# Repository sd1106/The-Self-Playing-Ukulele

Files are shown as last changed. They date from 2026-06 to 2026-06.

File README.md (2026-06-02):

# The-Self-Playing-Ukulele
An electromechanical ukulele that reads sheet music and plays it autonomously. Four stepper motors slide fretting carriages up and down the neck, four press servos fret the strings, and four strum servos pluck them. All electronics are coordinated by an ESP32-S3 microcontroller running firmware we wrote from scratch.

## How it works: 

1. PDF Sheet Music -> 
2. Optical Music Recognition (oemer) -> 
3. MusicXML mapped to music21 (Python) -> 
4. Note/Chord mapped to String + Fret mapping ->
5. Serial commands over USB -> 
6. ESP32-S3 Firmware ->
7. Stepper Motors (position)  +  Press Servos (fret)  +  Strum Servos (pluck)

## Mechanical System Description: 
Each of the four strings has its own independent carriage that rides along the neck on a timing belt driven by a 28BYJ-48 stepper motor. The carriage holds a press servo that swings up to 90 degrees to push the string down onto the fret, then returns to 0 degrees once the note has been strummed. A separate strum servo sits near the soundhole and alternates between two angles each time it fires. It tracks whether it's currently "in" or "out" and always moves to the opposite position, so it never tries to strum from the same direction twice.

Each string has its own lookup table of 14 timing values (milliseconds) representing how long the stepper needs to run to reach each fret from the home position (open/nut end). On startup, all carriages home to position zero. When a note is requested, the firmware:

1. Looks up the target fret's position in that string's table
2. Subtracts the current stored position to get the delta
3. Runs the motor forward (positive delta) or backward (negative delta) for that many milliseconds
4. Updates the stored current position

This means "string 3, fret 7" and "string 4, fret 7" will move different physical distances, because fret spacing and belt geometry differ per string, since each has its own calibrated table.

## Hardware Components:

- ESP32-S3-WROOM-1: Main microcontroller
- 28BYJ-48 stepper motor (x4): Move fretting carriage along the neck of the ukulele
- ULN2003 driver board (x4): Drive the steppers (4 GPIO pins each)
- 180° servo motor (x4): Strum strings (alternates direction each strike)
- 180° servo motor (x4): Press strings down onto frets (0°→90°→0°)
- 5V power supply: Powers steppers and servos

*Note: The ESP32-S3-WROOM-1 is used specifically. Pin assignments in the firmware reflect this. Pins 0, 3, 45, and 46 are avoided as they are strapping/reserved pins on this module.

## Software Components: 

#### The Arduino firmware: ukulele_riptide.ino 
The main firmware runs on the ESP32-S3 and handles all real-time motor control. 
Key behaviours:

- strumAll(): fires all four strum servos. Uses a global strumState boolean to alternate direction every call, so the servo always moves to the opposite of its current position
- pressG/C/E/A: each press servo goes to 60°–90° to fret, then returns to 0° after the chord is strummed
- Chord functions (Aminor(), G(), C()):  move the correct stepper carriages to position, set press angles, then call strummingRhythm()
- strummingRhythm(): plays the Riptide strumming pattern (down down, down-up-down with timed delays)
riptide(): sequences the three chords of Riptide (Am → G → C) and loops

#### Serial-Driven Instrument Controller (ukulele_controller.ino)
The production firmware is used in conjunction with the Python pipeline. Instead of a hardcoded song, it listens for serial commands and executes them in real time, giving the host PC full control over every actuator.

- Fret positioning: a lookup table maps each fret (0–12) to an absolute half-step count using equal-temperament geometry, so fret spacing compresses naturally toward the body. Coils are de-energised after each move to prevent the ULN2003 boards from overheating
- Strum alternation: each string tracks its own toggle, so consecutive strums always go in opposite directions
- CAL / DUMP commands: jog a carriage to any position and redefine zero without re-uploading firmware (CAL), or print a full live state table for debugging (DUMP)
- Boots by homing all carriages and parking all servos, then sends READY — the Python host waits for this before sending any commands

#### Python Pipeline: ukulele_player.py
Sits on the host PC and handles the sheet music side:

1. Opens a PDF and rasterises it to a 300 DPI PNG
2. Runs oemer (optical music recognition) to produce MusicXML
3. Parses the MusicXML with music21, extracting notes, chords, rests, and tempo
4. Maps each pitch to a (string, fret) pair using standard high-G ukulele tuning (G4 · C4 · E4 · A4), choosing whichever assignment minimises carriage travel
5. Voices chords across all four strings with a greedy least-travel algorithm
6. Sends MOVE, PLUCK, and HOME commands over USB serial in time with the score's tempo

## Libraries:

- ESP32Servo: Servo control via LEDC PWM on ESP32-S3
- Stepper (Arduino built-in): 28BYJ-48 stepper 
- controlmusic21 (Python): MusicXML parsing and score analysis
- pymupdf (Python): PDF rasterisation
- pyserial (Python): USB serial communication to ESP32

## Calibration:
Each string's fret timing table needs to be measured once on your physical build:

1. Upload firmware and open Serial Monitor
2. Send HOME — all carriages drive to the nut end limit switches
3. For each string, manually time (in milliseconds) how long the motor must run to reach each of the 14 frets from home
4. Update the lookup tables in the firmware constants at the top of ukulele_riptide.ino
5. Send DUMP over serial to verify stored positions, CAL to re-run calibration mode

Because fret spacing is not uniform (it compresses toward the body) and belt geometry differs per string, each of the four tables will have different values even for the same fret number.

### Built as a Computer Science capstone project, June 2026.

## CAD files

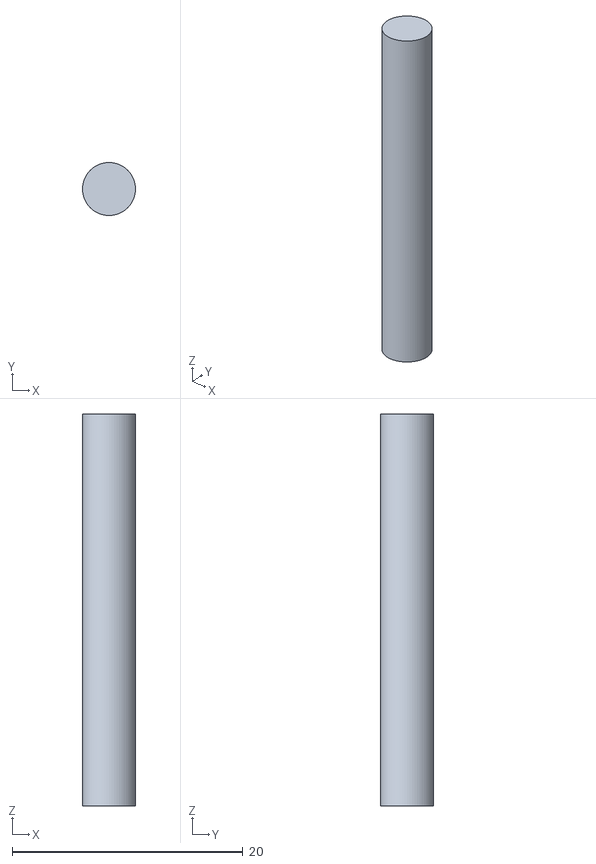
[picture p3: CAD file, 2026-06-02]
STL_Files/Axis.stl
4.60 x 4.60 x 34.0

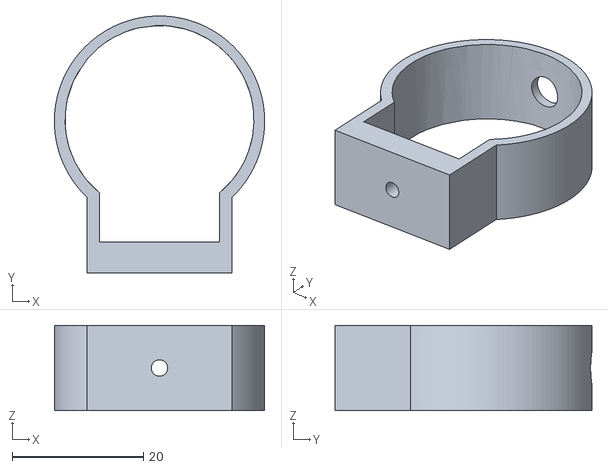
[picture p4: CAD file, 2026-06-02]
STL_Files/motor bracket.stl
32.0 x 39.1 x 13.0

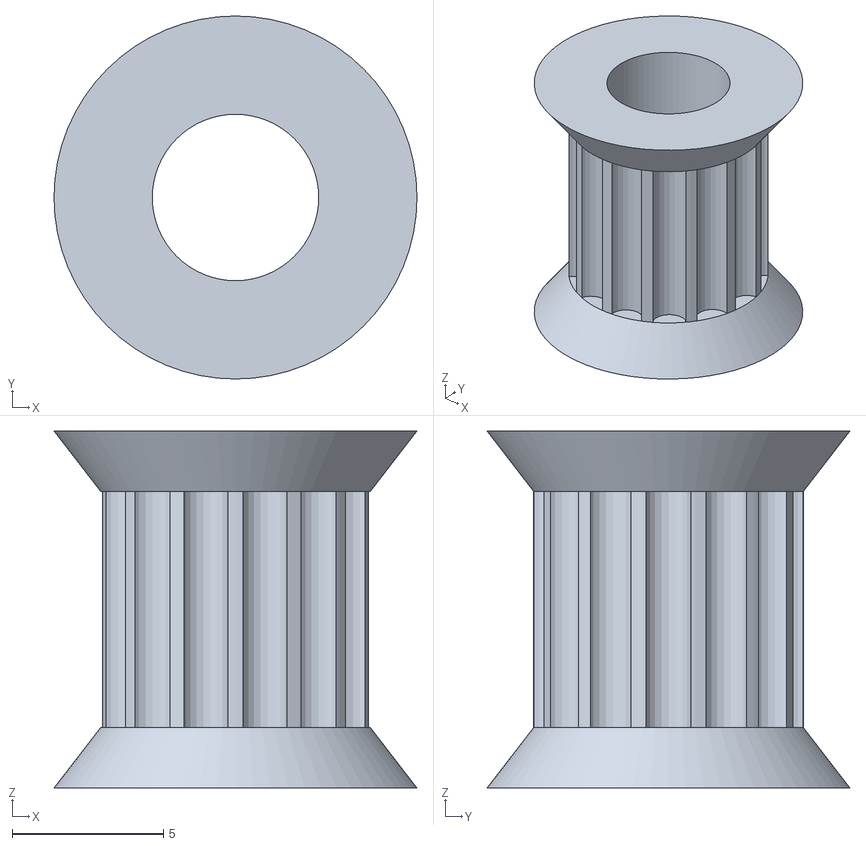
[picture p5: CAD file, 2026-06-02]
STL_Files/GT2 pully.stl
12.0 x 12.0 x 11.8

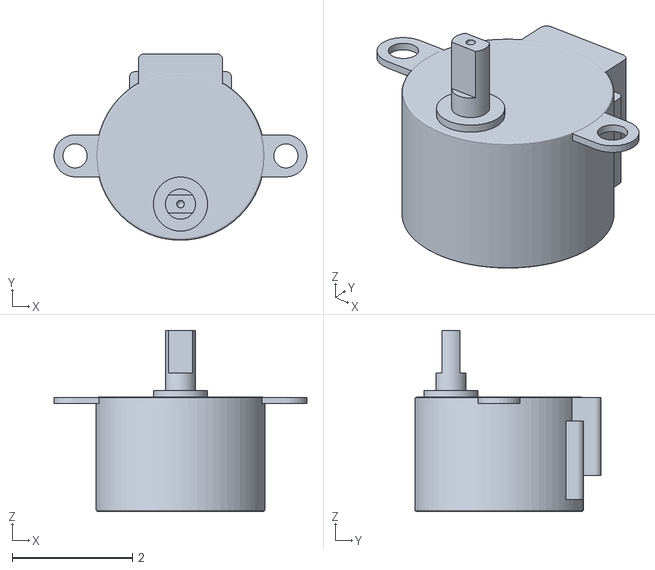
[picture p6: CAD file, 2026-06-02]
STL_Files/StepMotorModel.stl
4.20 x 3.10 x 3.01

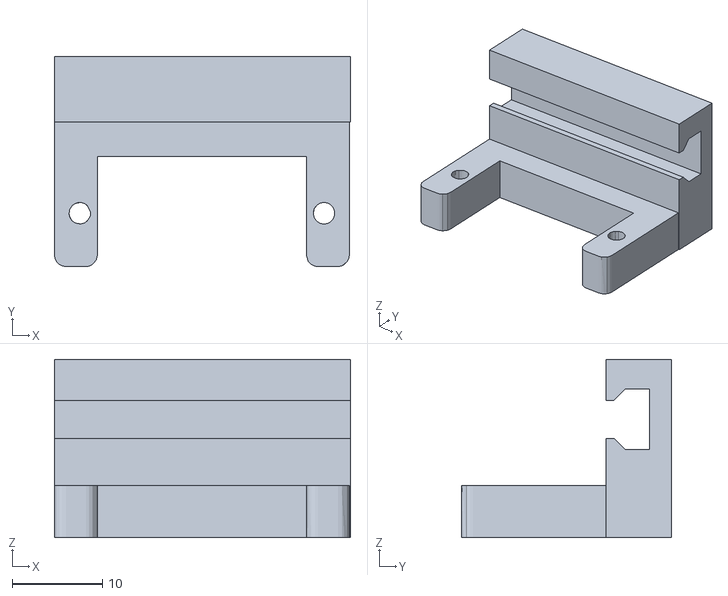
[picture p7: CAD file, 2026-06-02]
STL_Files/servo bracket.stl
32.7 x 23.2 x 19.7

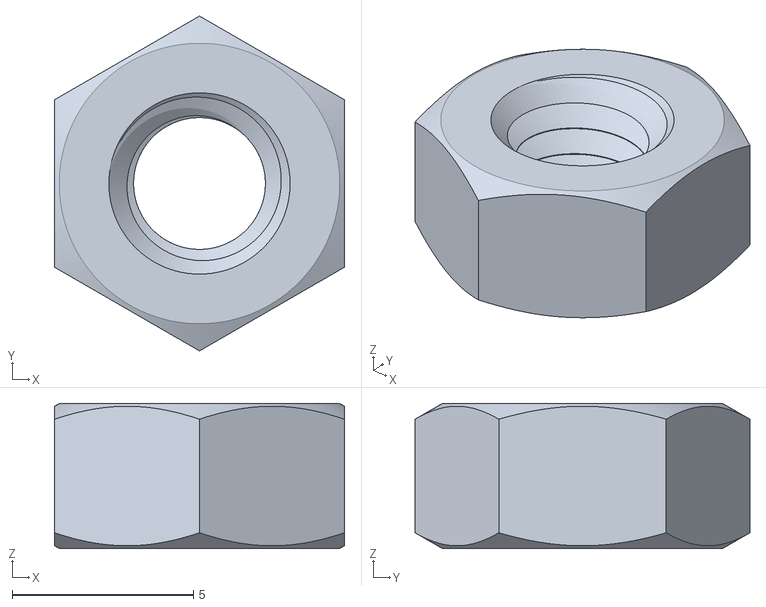
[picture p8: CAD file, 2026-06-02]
STL_Files/M5.stl
8.00 x 9.24 x 4.00

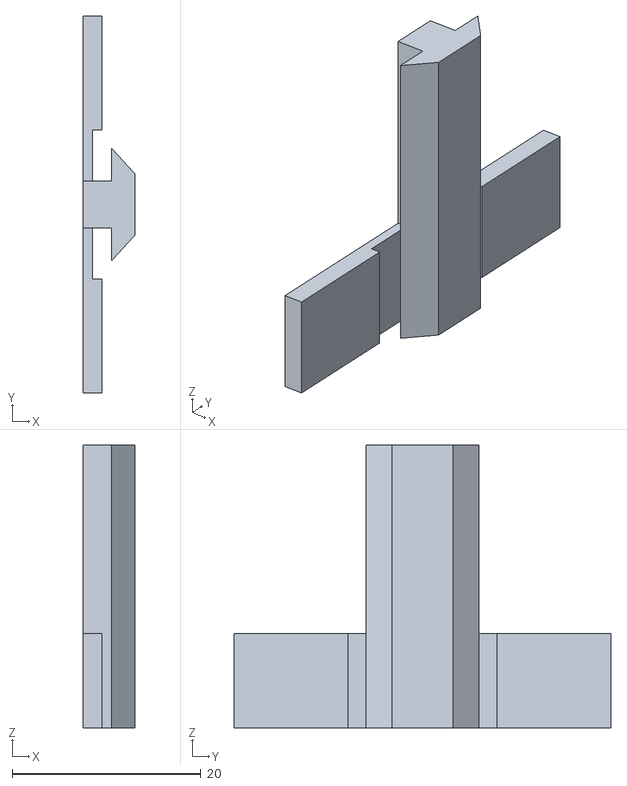
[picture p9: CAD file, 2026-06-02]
STL_Files/stepper_motor_thingy.stl
5.50 x 40.0 x 30.0

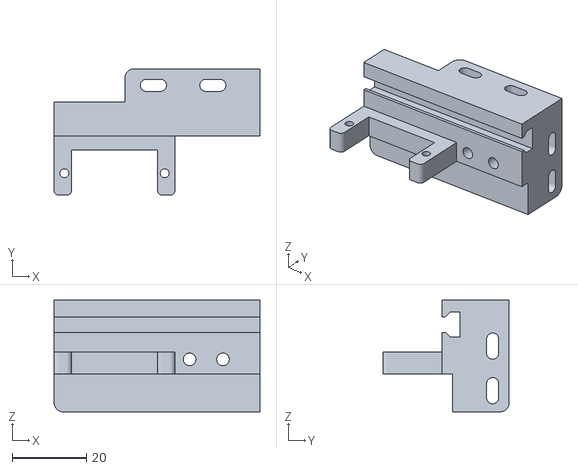
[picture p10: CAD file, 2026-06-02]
STL_Files/Motor_Bracket_Mini_Version (2).STL
55.5 x 34.0 x 30.1

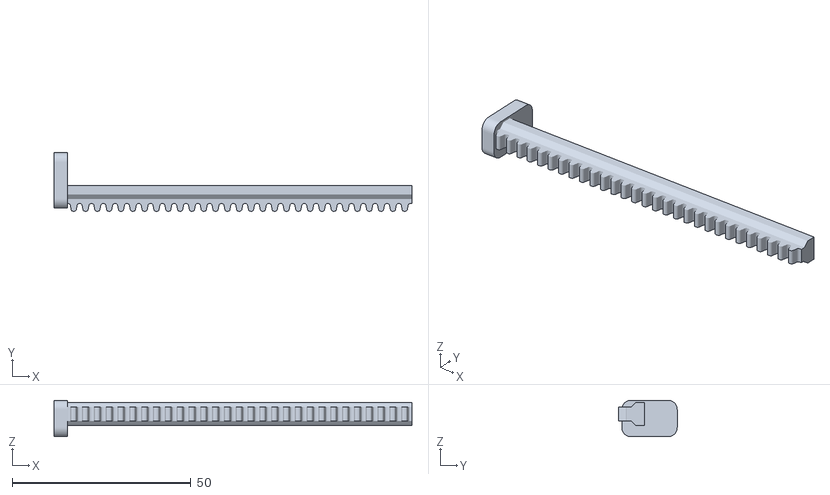
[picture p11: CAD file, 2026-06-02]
STL_Files/Pusher_100mm_Long.STL
100.0 x 16.3 x 10.2

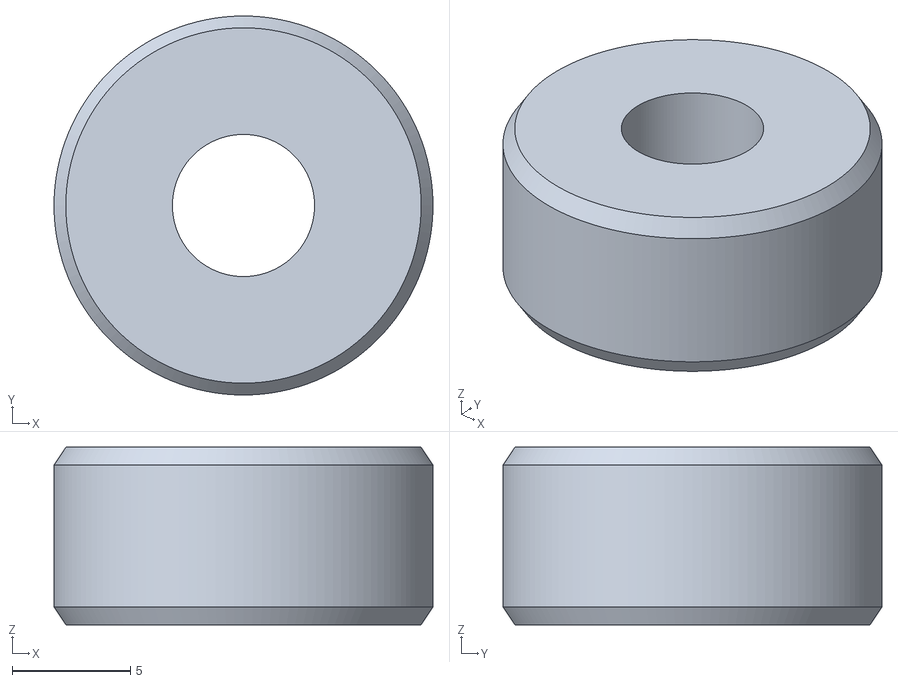
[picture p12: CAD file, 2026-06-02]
STL_Files/Glorious Elzing-Lappi.stl
16.0 x 16.0 x 7.50

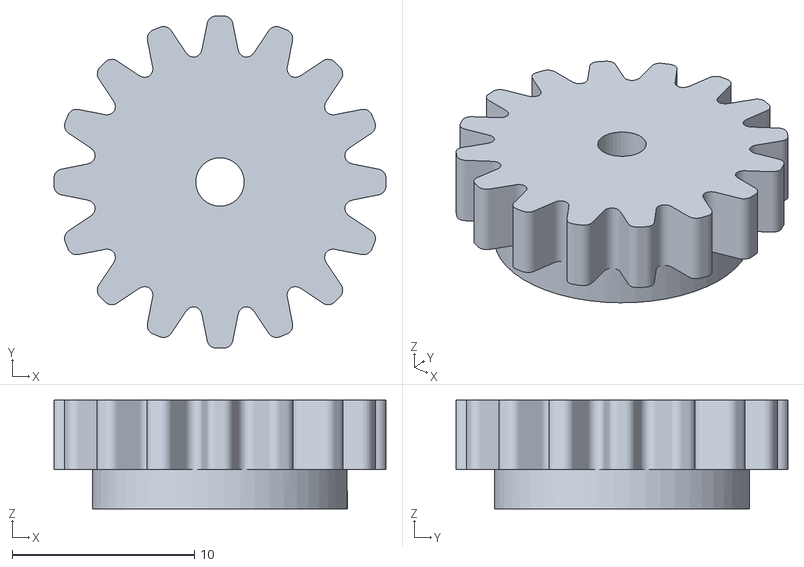
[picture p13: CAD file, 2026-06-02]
STL_Files/Pinion_Gear_Mini_Version (1).STL
18.2 x 18.2 x 5.97

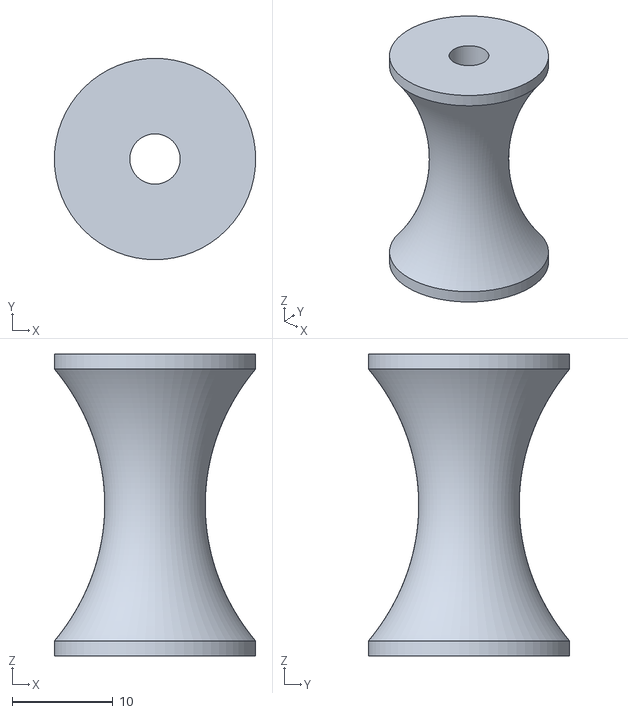
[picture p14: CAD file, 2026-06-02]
STL_Files/Roller.stl
20.0 x 20.0 x 30.0

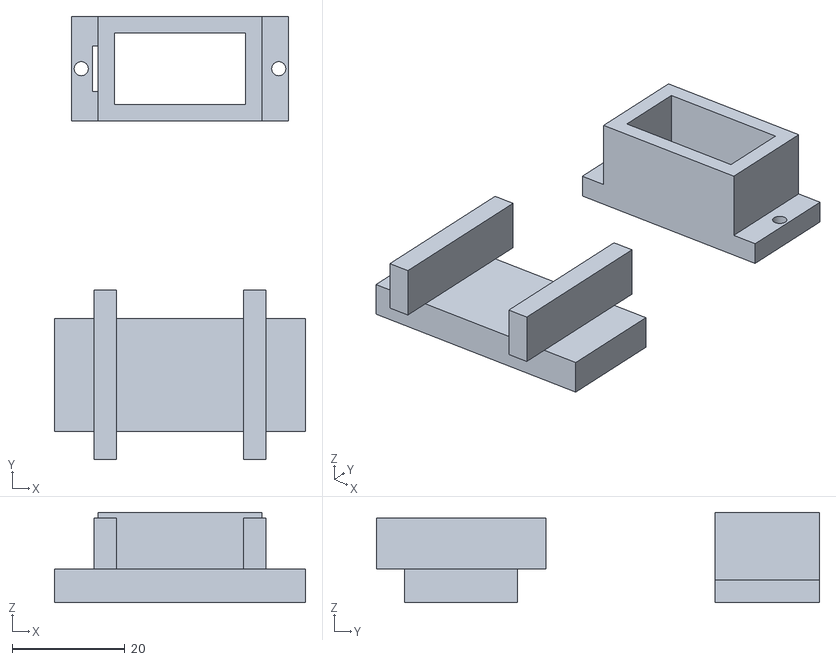
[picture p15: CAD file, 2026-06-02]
STL_Files/2Bracket.stl
44.5 x 78.5 x 16.0

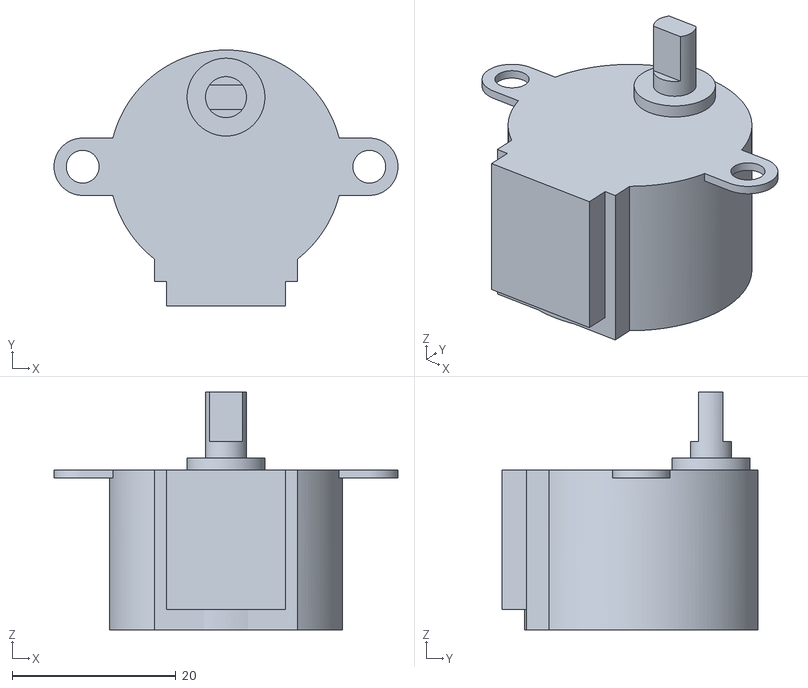
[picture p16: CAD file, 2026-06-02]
STL_Files/stepper_28byj-48.stl
42.0 x 31.2 x 29.0

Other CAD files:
STL_Files/24mm rode.stl
STL_Files/60mm rode.stl
STL_Files/5mm bolt.stl
STL_Files/9mm pusher.stl
STL_Files/Daring Robo-Fulffy (1).stl
STL_Files/Daring Robo-Fulffy (2).stl
STL_Files/Daring Robo-Fulffy (3).stl
STL_Files/Daring Robo-Fulffy (4).stl
STL_Files/Daring Robo-Fulffy (5).stl
STL_Files/Daring Robo-Fulffy (6).stl
STL_Files/Daring Robo-Fulffy.stl
STL_Files/Glorious Elzing-Lappi (1).stl
STL_Files/Glorious Elzing-Lappi (2).stl
STL_Files/Glorious Elzing-Lappi (3).stl
STL_Files/Glorious Elzing-Lappi (4).stl
STL_Files/Glorious Elzing-Lappi (5).stl
STL_Files/Glorious Elzing-Lappi (6).stl
STL_Files/Glorious Elzing-Lappi (7).stl
STL_Files/M5-25 (1).stl
STL_Files/M5-25.stl
STL_Files/M5_24_bolt.stl
STL_Files/M5_25_bolt.stl
STL_Files/M5_nut_normal.stl
STL_Files/M5_nut_thick.stl
STL_Files/M5_nut_thin.stl
STL_Files/Motor_Bracket_Large_Version.STL
STL_Files/Pusher_75mm_Long.STL
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

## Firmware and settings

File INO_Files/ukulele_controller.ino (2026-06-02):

/*
  ukulele_controller.ino
  Self-playing ukulele — ESP32-S3 firmware (serial-driven instrument driver)
  ===========================================================================
  TARGET: ESP32-S3-WROOM-1  (NOT classic ESP32 / ESP32-S2 — pins differ!)
  LIBRARY: ESP32Servo (madhephaestus, install via Library Manager)
           Requires Arduino-ESP32 core v3.0.0+. The S3 has only 8 LEDC
           channels (vs 16 on classic ESP32); recent ESP32Servo spills the
           extra servos onto the S3's MCPWM units so all 8 work.

  ┌──────────────────────────────────────────────────────────────────────────┐
  │ ESP32-S3-WROOM-1  WIRING TABLE                                            │
  ├──────────────────────────────────────────────────────────────────────────┤
  │ STEPPERS — 28BYJ-48 via ULN2003 (one driver board per string)            │
  │   String 0 (G):  IN1→GPIO4    IN2→GPIO5    IN3→GPIO6    IN4→GPIO7         │
  │   String 1 (C):  IN1→GPIO15   IN2→GPIO16   IN3→GPIO17   IN4→GPIO18        │
  │   String 2 (E):  IN1→GPIO8    IN2→GPIO9    IN3→GPIO10   IN4→GPIO11        │
  │   String 3 (A):  IN1→GPIO12   IN2→GPIO13   IN3→GPIO14   IN4→GPIO21        │
  │                                                                          │
  │ FRET SERVOS — press string down (signal wire only)                       │
  │   String 0 (G): GPIO1     String 1 (C): GPIO2                            │
  │   String 2 (E): GPIO41    String 3 (A): GPIO42                           │
  │                                                                          │
  │ STRUM SERVOS — alternating strum (signal wire only)                      │
  │   String 0 (G): GPIO39    String 1 (C): GPIO40                           │
  │   String 2 (E): GPIO47    String 3 (A): GPIO48                           │
  │                                                                          │
  │ POWER: drive the ULN2003 boards + all 8 servos from an EXTERNAL 5 V      │
  │        supply. Tie its GND to the ESP32-S3 GND. Do NOT run motors off    │
  │        the board's 3V3 pin.                                              │
  │                                                                          │
  │ PINS DELIBERATELY AVOIDED on the S3:                                     │
  │   0,3,45,46 = strapping   19,20 = native USB   43,44 = UART0 console     │
  │   26–37 = SPI flash / octal PSRAM (WROOM-1 N16R8)   38 = onboard RGB LED │
  │   (GPIO 22,23,24,25 do not physically exist on the ESP32-S3.)            │
  └──────────────────────────────────────────────────────────────────────────┘

  Each string has THREE actuators:
    • a 28BYJ-48 stepper that slides the fretting carriage along the neck
    • a fret servo that presses the string onto the fretboard at that position
    • a strum servo that plucks the string (alternates side each strum)

  Serial commands (115200 baud, newline-terminated)
  -------------------------------------------------
    FRET <str> <fret>          move carriage to <fret> (0..12) and press
    RELEASE <str>              lift the fret servo (open string)
    STRUM <str>                strum one string (auto-alternates direction)
    CHORD <f0> <f1> <f2> <f3>  fret all four strings at once (-1 = open)
    STRUMALL                   strum all four strings low→high
    HOME                       carriages to step 0, all frets released
    CAL <str> <steps>          jog carriage to absolute <steps> (calibration)
    CAL <str> ZERO             define current carriage position as step 0
    DUMP                       print live state + pin map
  (unknown commands are silently ignored)

  On boot the firmware homes/zeroes all carriages then prints "READY\n"
  (kept identical so the existing Python host's open_serial() still works).
*/

#include <Arduino.h>
#include <ESP32Servo.h>

// ── Pin definitions (ESP32-S3-WROOM-1 — see wiring table above) ───────────────

const uint8_t N_STRINGS = 4;

// Stepper coil pins: STEP_PIN[string][IN1..IN4] → ULN2003 IN1..IN4
const uint8_t STEP_PIN[N_STRINGS][4] = {
    {  4,  5,  6,  7 },   // String 0 (G) — ULN2003 #0
    { 15, 16, 17, 18 },   // String 1 (C) — ULN2003 #1
    {  8,  9, 10, 11 },   // String 2 (E) — ULN2003 #2
    { 12, 13, 14, 21 },   // String 3 (A) — ULN2003 #3
};

// Servo signal pins
const uint8_t FRET_SERVO_PIN[N_STRINGS]  = {  1,  2, 41, 42 };
const uint8_t STRUM_SERVO_PIN[N_STRINGS] = { 39, 40, 47, 48 };

// ── Fret step lookup table ────────────────────────────────────────────────────
// Absolute carriage position (in 28BYJ-48 half-steps) for each fret.
// Spacing follows equal-temperament fret geometry — steps[n] = K·(1 − 2^(−n/12))
// with K chosen so fret 12 (the octave) lands at 1024 half-steps. Frets bunch up
// as you climb the neck, exactly like a real fretboard. Re-calibrate with CAL.
const long FRET_STEPS[] = {
    0,    // open
    115,  // fret 1
    223,  // fret 2
    326,  // fret 3
    423,  // fret 4
    514,  // fret 5
    600,  // fret 6
    681,  // fret 7
    758,  // fret 8
    830,  // fret 9
    899,  // fret 10
    963,  // fret 11
    1024  // fret 12
};
const uint8_t MAX_FRET = (sizeof(FRET_STEPS) / sizeof(FRET_STEPS[0])) - 1;

// ── Servo angle constants ─────────────────────────────────────────────────────
const int FRET_REST   = 0;    // fret servo released (0°)
const int FRET_PRESS  = 90;   // fret servo pressing string down (90°)
const int STRUM_A     = 60;   // strum servo — one side of neutral
const int STRUM_B     = 120;  // strum servo — the other side of neutral

// ── Motion parameters ─────────────────────────────────────────────────────────
const uint16_t STEP_DELAY_US = 1200;  // per half-step; 28BYJ-48 is happy ~1–2 ms
const uint16_t FRET_SETTLE_MS = 120;  // let the fret servo seat before strumming
const uint16_t STRUM_SETTLE_MS = 90;  // let the strum servo finish its sweep

// ── Hardware objects ──────────────────────────────────────────────────────────
Servo fretServo[N_STRINGS];
Servo strumServo[N_STRINGS];

// ── State ─────────────────────────────────────────────────────────────────────
long    carriagePos[N_STRINGS] = { 0, 0, 0, 0 };   // current absolute half-steps
uint8_t phaseIdx[N_STRINGS]    = { 0, 0, 0, 0 };    // index into HALF_STEP[]
bool    fretPressed[N_STRINGS] = { false, false, false, false };
bool    strumToggle[N_STRINGS] = { false, false, false, false }; // last strum side

// 28BYJ-48 half-step sequence. Bit3=IN1, Bit2=IN2, Bit1=IN3, Bit0=IN4.
const uint8_t HALF_STEP[8] = {
    0b1000, 0b1100, 0b0100, 0b0110,
    0b0010, 0b0011, 0b0001, 0b1001
};

// ── Low-level stepper helpers ─────────────────────────────────────────────────

// Energise the four coils of string s according to half-step phase `idx`.
void applyPhase(uint8_t s, uint8_t idx) {
    uint8_t bits = HALF_STEP[idx & 7];
    for (uint8_t p = 0; p < 4; p++) {
        digitalWrite(STEP_PIN[s][p], (bits >> (3 - p)) & 0x01);
    }
}

// De-energise all coils of string s (prevents the ULN2003 from cooking while
// idle — the gearbox friction + fret servo hold position, not the coils).
void releaseCoils(uint8_t s) {
    for (uint8_t p = 0; p < 4; p++) digitalWrite(STEP_PIN[s][p], LOW);
}

// Drive string s's carriage to an absolute half-step position.
void moveCarriage(uint8_t s, long target) {
    long delta = target - carriagePos[s];
    int  dir   = (delta >= 0) ? 1 : -1;
    long steps = labs(delta);

    for (long i = 0; i < steps; i++) {
        phaseIdx[s] = (uint8_t)((phaseIdx[s] + dir + 8) & 7);
        applyPhase(s, phaseIdx[s]);
        delayMicroseconds(STEP_DELAY_US);
        carriagePos[s] += dir;
    }
    releaseCoils(s);
}

// ── Fret / strum helpers ──────────────────────────────────────────────────────

void releaseFretString(uint8_t s) {
    fretServo[s].write(FRET_REST);
    fretPressed[s] = false;
}

// Move carriage to `fret` and press the string down. fret < 0 = open string.
void fretString(uint8_t s, int fret) {
    if (fret < 0) {
        releaseFretString(s);
        return;
    }
    if (fret > MAX_FRET) fret = MAX_FRET;
    moveCarriage(s, FRET_STEPS[fret]);
    fretServo[s].write(FRET_PRESS);
    fretPressed[s] = true;
}

// Strum one string. The servo flips to the OPPOSITE side every call, so two
// consecutive strums are always in opposite directions — never the same way
// twice in a row.
void strumString(uint8_t s) {
    strumToggle[s] = !strumToggle[s];
    strumServo[s].write(strumToggle[s] ? STRUM_B : STRUM_A);
    delay(STRUM_SETTLE_MS);
}

// Fret an entire chord. fret[] holds 4 values, one per string (-1 = open).
void fretChord(const int fret[N_STRINGS]) {
    for (uint8_t s = 0; s < N_STRINGS; s++) fretString(s, fret[s]);
    delay(FRET_SETTLE_MS);
}

void homeAll() {
    for (uint8_t s = 0; s < N_STRINGS; s++) {
        releaseFretString(s);
        moveCarriage(s, 0);
    }
}

// ── Diagnostics ───────────────────────────────────────────────────────────────

void dumpState() {
    Serial.println(F("── ukulele state ─────────────────────────────"));
    Serial.println(F("str  carriage  fret  pressed  strumSide"));
    for (uint8_t s = 0; s < N_STRINGS; s++) {
        // nearest fret for the current carriage position (display only)
        uint8_t nf = 0;
        for (uint8_t f = 0; f <= MAX_FRET; f++)
            if (labs(FRET_STEPS[f] - carriagePos[s]) <
                labs(FRET_STEPS[nf] - carriagePos[s])) nf = f;

        Serial.printf("  %u  %8ld   %3u    %-5s     %c\n",
                      s, carriagePos[s], nf,
                      fretPressed[s] ? "yes" : "no",
                      strumToggle[s] ? 'B' : 'A');
    }
    Serial.println(F("pins  IN1/IN2/IN3/IN4   fretSrv  strumSrv"));
    for (uint8_t s = 0; s < N_STRINGS; s++) {
        Serial.printf("  %u   %2u/%2u/%2u/%2u       %3u      %3u\n",
                      s, STEP_PIN[s][0], STEP_PIN[s][1], STEP_PIN[s][2],
                      STEP_PIN[s][3], FRET_SERVO_PIN[s], STRUM_SERVO_PIN[s]);
    }
    Serial.println(F("──────────────────────────────────────────────"));
}

// ── Command parser ────────────────────────────────────────────────────────────

void handleCommand(const String& cmd) {
    if (cmd.startsWith("FRET ")) {
        int sp = cmd.indexOf(' ', 5);
        uint8_t s = (uint8_t) cmd.substring(5, sp).toInt();
        int fret  = cmd.substring(sp + 1).toInt();
        if (s < N_STRINGS) fretString(s, fret);

    } else if (cmd.startsWith("RELEASE ")) {
        uint8_t s = (uint8_t) cmd.substring(8).toInt();
        if (s < N_STRINGS) releaseFretString(s);

    } else if (cmd.startsWith("STRUM ")) {
        uint8_t s = (uint8_t) cmd.substring(6).toInt();
        if (s < N_STRINGS) strumString(s);

    } else if (cmd == "STRUMALL") {
        for (uint8_t s = 0; s < N_STRINGS; s++) strumString(s);

    } else if (cmd.startsWith("CHORD ")) {
        // CHORD <f0> <f1> <f2> <f3>
        int fret[N_STRINGS];
        int idx = 6;
        for (uint8_t s = 0; s < N_STRINGS; s++) {
            int sp = cmd.indexOf(' ', idx);
            String tok = (sp < 0) ? cmd.substring(idx) : cmd.substring(idx, sp);
            fret[s] = tok.toInt();
            idx = (sp < 0) ? cmd.length() : sp + 1;
        }
        fretChord(fret);

    } else if (cmd == "HOME") {
        homeAll();
        Serial.println("HOMED");

    } else if (cmd.startsWith("CAL ")) {
        // CAL <str> <steps>   or   CAL <str> ZERO
        int sp = cmd.indexOf(' ', 4);
        uint8_t s = (uint8_t) cmd.substring(4, sp).toInt();
        String arg = cmd.substring(sp + 1);
        arg.trim();
        if (s < N_STRINGS) {
            if (arg == "ZERO") {
                carriagePos[s] = 0;                 // redefine home here
                Serial.printf("CAL str %u zeroed\n", s);
            } else {
                moveCarriage(s, arg.toInt());       // jog to absolute steps
                Serial.printf("CAL str %u @ %ld steps\n", s, carriagePos[s]);
            }
        }

    } else if (cmd == "DUMP") {
        dumpState();
    }
    // Unknown commands silently ignored
}

// ── Arduino setup & loop ──────────────────────────────────────────────────────

void setup() {
    Serial.begin(115200);

    // ESP32Servo: reserve all four LEDC timers up front so the 8 servos can be
    // distributed across LEDC + MCPWM on the S3.
    ESP32PWM::allocateTimer(0);
    ESP32PWM::allocateTimer(1);
    ESP32PWM::allocateTimer(2);
    ESP32PWM::allocateTimer(3);

    for (uint8_t s = 0; s < N_STRINGS; s++) {
        for (uint8_t p = 0; p < 4; p++) {
            pinMode(STEP_PIN[s][p], OUTPUT);
            digitalWrite(STEP_PIN[s][p], LOW);
        }
        fretServo[s].setPeriodHertz(50);
        fretServo[s].attach(FRET_SERVO_PIN[s], 500, 2400);
        strumServo[s].setPeriodHertz(50);
        strumServo[s].attach(STRUM_SERVO_PIN[s], 500, 2400);

        fretServo[s].write(FRET_REST);
        strumServo[s].write(STRUM_A);   // park strummers on side A
    }

    homeAll();

    Serial.println("READY");   // Python host waits for exactly this string
}

void loop() {
    if (Serial.available()) {
        String line = Serial.readStringUntil('\n');
        line.trim();
        if (line.length() > 0) handleCommand(line);
    }
}

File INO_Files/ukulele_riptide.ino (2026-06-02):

#include <Stepper.h>
#include <ESP32Servo.h>

Stepper motorG(2048, 7, 5, 6, 4);
Stepper motorC(2048, 10, 15, 16, 17);
Stepper motorE(2048, 38, 39, 40, 41);
Stepper motorA(2048, 45, 46, 47, 48);

bool strumState = false;
bool once = true; 

Servo pressG;
Servo strumG;
Servo pressC;
Servo strumC;
Servo pressE;
Servo strumE;
Servo pressA;
Servo strumA;

void setup() {
  motorG.setSpeed(15);
  motorC.setSpeed(15);
  motorE.setSpeed(15);
  motorA.setSpeed(15);

  pressG.attach(1);
  strumG.attach(2);
  
  pressC.attach(8);
  strumC.attach(9);
  pressE.attach(18);
  strumE.attach(21);
  pressA.attach(42);
  strumA.attach(3);

  pressG.write(0);
  strumG.write(0);
  pressC.write(0);
  strumC.write(0);
  pressE.write(0);
  strumE.write(0);
  pressA.write(0);
  strumA.write(0);
  delay(1000);
  strumC.write(60);
}
void loop() {
    if(once)
    {
        riptide();
        once = false;
    }
}

void riptide(){
    Aminor();
    strummingRhythm();
    pressG.write(0);
    delay(300);
    
    G();
    strummingRhythm();
    pressC.write(0);
    pressE.write(60);
    pressA.write(60);
    delay(300);
    
    C();
    strummingRhythm();
    pressA.write(60);
    delay(300);
}

void strummingRhythm(){
    strumAll();
    delay(1000);
    strumAll();
    delay(1000);

    strumAll();
    delay(500);
    strumAll();
    delay(500);
    strumAll();
    delay(500);
}

void strumAll(){
    int targetAngle;
    if(strumState == false)
    {
        targetAngle = 90;
        strumState = true;
    }
    else
    {
        targetAngle = 0;
        strumState = false;
    }
    strumG.write(targetAngle);
    strumC.write(targetAngle);
    strumE.write(targetAngle);
    strumA.write(targetAngle);
}

void Aminor(){
    motorG.step(-6000);
    pressG.write(60);
    delay(300);
}

void G(){
    motorC.step(-6000);
    motorE.step(5000);
    motorA.step(6000);
    pressC.write(120);
    pressE.write(0);
    pressA.write(0);
    delay(300);
}

void GOpposite(){
    motorC.step(-6000);
    motorE.step(-5000);
    motorA.step(-6000);
    pressC.write(0);
    pressE.write(60);
    pressA.write(60);
    delay(300); 
}

void C(){
    motorA.step(-1000);
    pressA.write(0);
    delay(300);
}
